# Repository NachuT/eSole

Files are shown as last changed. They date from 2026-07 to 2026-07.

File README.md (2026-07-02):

# eSole
## The idea

All of these moments were showstopping and unexpected moments in the NBA for the wrong reasons. When the sports entertainment industry id built around creating these emotions: Achilles Tears, ACL injuries, and permanent knee issues were not how they intended to create those emotions. Like many injuries, leg injuries as well benefit greatly from early detection but many players and people too don't know when things start to go wrong until they actually do. If only there was a unnoticable shoesole that can tell atheletes and people what is wrong with their mechanics.

## Now there is!

eSole is a flex PCB + Rigid PCB that measures capacitance between 2 halves of the flex PCB around foam to detect when and where pressure on the foot is being applied and where it is being applied.

Features:
- ESP32 for processing and sending analytics via bluetooth
- Both halves of the flexpcb integrated into 1 for cost
- MRP121 for sending capacitance values via I2C
- A case that is easily removable
- Power managment so the device can use a lipo but can be charged + programmed via USB-C

## Images 
PCB Footsole -



3d View Footsole-



Schematic Transmitter (ESP32 Based)-



PCB Transmitter(ESP32 Based)-



3D View PCB Transmitter(ESP32 Based)-



PCB Transmitter(ESP32 Baesed) With Case-

Screenshot 2026-07-01 at 2 05 06 AM

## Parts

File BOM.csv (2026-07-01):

Name | Price | Notes
Both PCBs | 181.37 | The rigid pcb is really optimized but the flex pcb super expensive
Shipping | 46 | For both PCBs
Customs | 60 | For both PCBs
Discount | -10 | For the PCBs
Sales Tax | 18 | For the PCBs
LiPo | 8 | https://www.amazon.com/battery-Rechargeable-Lithium-Polymer-Connector/dp/B07BTT6N48
Neoprene(best conductive foam) | 18 | https://www.homedepot.com/p/Rubber-Cal-Closed-Cell-Sponge-Rubber-Neoprene-1-16-in-x-39-in-x-78-in-Black-Foam-Rubber-Sheet-02-128-0062/304363420
- | - | -
Total | 325

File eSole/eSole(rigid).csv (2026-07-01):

Item # | Quantity per board | Comment | Reference designators | Footprint | Value | Manufacturer Part | Manufacturer | Supplier Part | Supplier | Unique ID | Pin Count | Category | LCSC Stock | LCSC Price | JLCPCB Stock | JLCPCB Price | Layer | Mounting Style | Add into BOM | Convert to PCB | 3D Model Title | Device | Name | 3D Model Transform | JLCPCB Part Class | Description | sourceId | spicePre
1 | 7 | 100nF | C1,C2,C5,C7,C13,C15,C16 | C0402 | 100nF | CL05B104KO5NNNC | SAMSUNG(三星) | C1525 | LCSC | gge14,gge15,gge20,gge20_0,gge20_1,gge20_3,gge20_4 | 2 | Capacitors:Multilayer Ceramic Capacitors MLCC - SMD/SMT |  |  | 30747172 | 0.0004 | T | SMT | yes |  | C0402_L1.0-W0.5-H0.5 | CL05B104KO5NNNC | 100nF | 39.37,19.685,0,0,0,0,0,0,0 | Basic Part | Capacitance:100nF Tolerance:±10% Tolerance:±10% Voltage Rating:16V Temperature Coefficient:X7R
2 | 6 | 1uF | C3,C4,C6,C8,C12,C14 | C0402 | 1uF | CL05A105KA5NQNC | SAMSUNG(三星) | C52923 | LCSC | gge16,gge17,gge21,gge21_0,gge21_1,gge21_2 | 2 | Capacitors:Multilayer Ceramic Capacitors MLCC - SMD/SMT |  |  | 9758515 | 0.0033 | T | SMT | yes |  | C0402_L1.0-W0.5-H0.5 | CL05A105KA5NQNC | 1uF | 39.37,19.685,0,0,0,0,0,0,0 | Basic Part | Capacitance:1uF Tolerance:±10% Tolerance:±10% Voltage Rating:25V Temperature Coefficient:X5R
3 | 2 | 4.7uF | C9,C10 | C0402 | 4.7uF | CL05A475MP5NRNC | SAMSUNG(三星) | C23733 | LCSC | gge24,gge25 | 2 | Capacitors:Multilayer Ceramic Capacitors MLCC - SMD/SMT |  |  | 2176604 | 0.0045 | T | SMT | yes |  | C0402_L1.0-W0.5-H0.5 | CL05A475MP5NRNC | 4.7uF | 39.37,19.685,0,0,0,0,0,0,0 | Basic Part | Capacitance:4.7uF Tolerance:±20% Tolerance:±20% Voltage Rating:10V Temperature Coefficient:X5R
4 | 1 | 10uF | C11 | C0603 | 10uF | CL10A106KP8NNNC | SAMSUNG(三星) | C19702 | LCSC | gge27 | 2 | Capacitors:Multilayer Ceramic Capacitors MLCC - SMD/SMT |  |  | 5635641 | 0.0065 | T | SMT | yes |  | C0603_L1.6-W0.8-H0.8 | CL10A106KP8NNNC | 10uF | 62.992,31.496,0,0,0,0,0,0,0 | Basic Part | Capacitance:10uF Tolerance:±10% Tolerance:±10% Voltage Rating:10V Temperature Coefficient:X5R
5 | 1 | S2B-PH-SM4-TB(LF)(SN) | CN1 | CONN-SMD_P2.00_S2B-PH-SM4-TB-LF-SN |  | S2B-PH-SM4-TB(LF)(SN) | JST | C295747 | LCSC | gge6 | 4 | Connectors:Wire To Board Connector |  |  | 99038 | 0.0303 | T | SMT | yes |  | CONN-SMD_P2.00_S2B-PH-SM4-TB-LF-SN | S2B-PH-SM4-TB(LF)(SN) | S2B-PH-SM4-TB(LF)(SN) | 311.023,338.582,0,0,0,0,0,-3.937,0 | Extended Part | Pins Structure:1x2P Pitch:2mm Mounting Style:Horizontal attachment Reference Series:PH Number of Pins:2P Number of Rows:1 Number of PINs Per Row:2 Row Spacing:- Current Rating (Max):2A Contact Material:Copper alloy Contact Plating:Tin Operating Temperatur
6 | 2 | SS34 | D1,D2 | SMA_L4.3-W2.6-LS5.2-RD |  | SS34 | MDD(辰达半导体) | C8678 | LCSC | gge12,gge13 | 2 | Diodes:Schottky Diodes |  |  | 3261153 | 0.0047 | T | SMT | yes |  | SMA_L4.3-W2.6-LS5.2-RD | SS34_C8678 | SS34 | 185.039,102.362,0,0,0,0,0,0,0 | Basic Part | Diode Configuration:Independent Voltage - Forward(Vf@If):550mV@3A Voltage - DC Reverse(Vr):40V Current - Rectified:3A Reverse Leakage Current (Ir):500uA@40V Operating Junction Temperature Range:-55℃~+125℃ Operating Junction Temperature Range:-55℃~+125℃
7 | 1 | FPC-05F-12PH20 | FPC1 | FPC-SMD_12P-P0.50_FPC-05F-12PH20 |  | FPC-05F-12PH20 | XUNPU(讯普) | C2856799 | LCSC | gge2 | 14 | Connectors:FFC, FPC (Flat Flexible) Connector Assemblies |  |  | 123048 | 0.0154 | T | SMT | yes |  | FPC-SMD_12P-P0.50_FPC-05F-12PH20 | FPC-05F-12PH20 | FPC-05F-12PH20 | 409.448,201.5744,0,0,0,0,0,-47.244,0 | Extended Part | Locking Feature:Hinged Lid Contact Type:Surface Mount Number of Contacts:12P Pitch:0.5mm Mounting Type:Bottom Contact FFC, FCB Thickness:0.3mm FFC, FCB Thickness:0.3mm Height Above Board:2mm Contact Material:Phosphor Bronze Contact Plating:Tin Operating T
8 | 1 | KT-0603W | LED1 | LED0603-R-RD_WHITE |  | KT-0603W | KENTO | C2290 | LCSC | gge26 | 2 | Optoelectronics:LED Indication - Discrete |  |  | 1996819 | 0.0019 | T | SMT | yes |  | LED0603-R-RD_WHITE | KT-0603W | KT-0603W | 63.7794,31.496,0,0,0,0,0,0,0 | Basic Part | Lamp Holder Type:1.6mm x 0.8mm square LED Illumination Color:White Voltage - Forward(Vf):2.6V~3.1V Voltage - Forward(Vf):2.6V~3.1V Power(Watts):100mW Forward Current:5mA Wavelength - Dominant:- Wavelength - Dominant:- Peak Wavelength:- Peak Wavelength:- D
9 | 2 | 5.1kΩ | R1,R2 | R0402 | 5.1kΩ | 0402WGF5101TCE | UNI-ROYAL(厚声) | C25905 | LCSC | gge10,gge11 | 2 | Resistors:Chip Resistor - Surface Mount |  |  | 1798751 | 0.0002 | T | SMT | yes |  | R0402_L1.0-W0.5-H0.4 | 0402WGF5101TCE | 5.1kΩ | 39.37,19.685,0,0,0,0,0,0,0 | Basic Part | Type:Thick Film Resistor Resistance:5.1kΩ Tolerance:±1% Tolerance:±1% Power(Watts):62.5mW Voltage-Supply(Max):50V Temperature Coefficient:±100ppm/℃ Temperature Coefficient:±100ppm/℃ Operating Temperature:-55℃~+155℃ Operating Temperature:-55℃~+155℃
10 | 2 | 0Ω | R3,R4 | R0402 | 0Ω | 0402WGF0000TCE | UNI-ROYAL(厚声) | C17168 | LCSC | gge18,gge19 | 2 | Resistors:Chip Resistor - Surface Mount |  |  | 2705757 | 0.0003 | T | SMT | yes |  | R0402_L1.0-W0.5-H0.4 | 0402WGF0000TCE | 0Ω | 39.37,19.685,0,0,0,0,0,0,0 | Basic Part | Type:Thick Film Resistor Resistance:0Ω Tolerance:±1% Tolerance:±1% Power(Watts):62.5mW Voltage-Supply(Max):50V Temperature Coefficient:±800ppm/℃ Temperature Coefficient:±800ppm/℃ Operating Temperature:-55℃~+155℃ Operating Temperature:-55℃~+155℃
11 | 1 | 2kΩ | R5 | R0402 | 2kΩ | 0402WGF2001TCE | UNI-ROYAL(厚声) | C4109 | LCSC | gge22 | 2 | Resistors:Chip Resistor - Surface Mount |  |  | 1410006 | 0.0002 | T | SMT | yes |  | R0402_L1.0-W0.5-H0.4 | 0402WGF2001TCE | 2kΩ | 39.37,19.685,0,0,0,0,0,0,0 | Basic Part | Type:Thick Film Resistors Resistance:2kΩ Tolerance:±1% Tolerance:±1% Power(Watts): Overload Voltage (Max): Temperature Coefficient:±100ppm/℃ Temperature Coefficient:±100ppm/℃ Operating Temperature Range:-55℃~+155℃ Operating Temperature Range:-55℃~+155℃
12 | 1 | 470Ω | R6 | R0402 | 470Ω | 0402WGF4700TCE | UNI-ROYAL(厚声) | C25117 | LCSC | gge23 | 2 | Resistors:Chip Resistor - Surface Mount |  |  | 501753 | 0.0002 | T | SMT | yes |  | R0402_L1.0-W0.5-H0.4 | 0402WGF4700TCE | 470Ω | 39.37,19.685,0,0,0,0,0,0,0 | Basic Part | Type:Thick Film Resistor Resistance:470Ω Tolerance:±1% Tolerance:±1% Power(Watts):62.5mW Voltage-Supply(Max):50V Temperature Coefficient:±100ppm/℃ Temperature Coefficient:±100ppm/℃ Operating Temperature:-55℃~+155℃ Operating Temperature:-55℃~+155℃
13 | 2 | 10kΩ | R7,R8 | R0402 | 10kΩ | 0402WGF1002TCE | UNI-ROYAL(厚声) | C25744 | LCSC | gge28,gge29 | 2 | Resistors:Chip Resistor - Surface Mount |  |  | 217303 | 0.0005 | T | SMT | yes |  | R0402_L1.0-W0.5-H0.4 | 0402WGF1002TCE | 10kΩ | 39.37,19.685,0,0,0,0,0,0,0 | Basic Part | Type:Thick Film Resistor Resistance:10kΩ Tolerance:±1% Tolerance:±1% Power(Watts):62.5mW Voltage-Supply(Max):50V Temperature Coefficient:±100ppm/℃ Temperature Coefficient:±100ppm/℃ Operating Temperature:-55℃~+155℃ Operating Temperature:-55℃~+155℃
14 | 1 | 75kΩ | R9 | R0603 | 75kΩ | 0603WAF7502T5E | UNI-ROYAL(厚声) | C23242 | LCSC | gge30 | 2 | Resistors:Chip Resistor - Surface Mount |  |  | 199044 | 0.0003 | T | SMT | yes |  | R0603 | 0603WAF7502T5E | 75kΩ | 31.8897,63.7794,0,90,0,0,0,0,0 | Basic Part | Type:Thick Film Resistor Resistance:75kΩ Tolerance:±1% Tolerance:±1% Power(Watts):100mW Voltage-Supply(Max):75V Temperature Coefficient:±100ppm/℃ Temperature Coefficient:±100ppm/℃ Operating Temperature:-55℃~+155℃ Operating Temperature:-55℃~+155℃
15 | 2 | 4.7kΩ | R10,R11 | R0805 | 4.7kΩ | 0805W8F4701T5E | UNI-ROYAL(厚声) | C17673 | LCSC | gge31,gge32 | 2 | Resistors:Chip Resistor - Surface Mount |  |  | 2978214 | 0.0005 | T | SMT | yes |  | R0805_L2.0-W1.3-H0.6 | 0805W8F4701T5E | 4.7kΩ | 78.74,51.181,0,0,0,0,0,-0.0005,0 | Basic Part | Type:Thick Film Resistors Resistance:4.7kΩ Tolerance:±1% Tolerance:±1% Power(Watts): Overload Voltage (Max): Temperature Coefficient:±100ppm/℃ Temperature Coefficient:±100ppm/℃ Operating Temperature Range:-55℃~+155℃ Operating Temperature Range:-55℃~+155℃
16 | 2 | TS-1088-AR02016 | SW1,SW2 | SW-SMD_L3.9-W3.0-P4.45 |  | TS-1088-AR02016 | XUNPU(讯普) | C720477 | LCSC | gge4,gge5 | 2 | Switches:Tactile Switches |  |  | 871138 | 0.0083 | T | SMT | yes |  | SW-SMD_L3.9-W2.9-H2.0-LS4.8 | TS-1088-AR02016 | TS-1088-AR02016 | 188.976,114.174,0,0,0,0,0,0,0 | Basic Part | Circuit:SPST Actuator Style:Round Button Operating Force:1.6N Mounting Type:Surface Mount,Vertical Length:3.9mm Width:3mm Switch Height:2mm with Bracket:Without Bracket Contact Current:50mA Voltage Rating:12V Actuator/Cap Color:Black With Lamp:- IP Rating
17 | 1 | 2.4GHz | U1 | WIFIM-SMD_ESP32-S3-WROOM-1-N8 | 2.4GHz | ESP32-S3-WROOM-1-N8 | ESPRESSIF(乐鑫) | C2913198 | LCSC | gge1 | 49 | IoT/Communication Modules:WiFi Modules |  |  | 7521 | 0.7148 | T | SMT | yes |  | WIFIM-SMD_ESP32-S3-WROOM-1-N8 | ESP32-S3-WROOM-1-N8 | 2.4GHz | 708.66,1003.935,0,0,0,0,0,145.669,0 | Extended Part | Utilized IC / Part:ESP32-S3 Chip Wireless Standard:Bluetooth5.0 Interface Type:SPI；I2S；USB；I2C；UART Frequency:2.4GHz Antenna Type:On-board PCB Antenna Output Power:20.5dBm Output Power:20.5dBm Voltage - Supply:3V~3.6V Voltage - Supply:3V~3.6V Receive Cur
18 | 1 | MPR121QR2 | U2 | QFN-20_L3.0-W3.0-P0.40-BL |  | MPR121QR2 | NXP(恩智浦) | C91322 | LCSC | gge7 | 20 | Sensors:Touch Sensors |  |  | 1879 | 0.3987 | T | SMT | yes |  | QFN-20_L3.0-W3.0-H0.6-P0.40-BL | MPR121QR2 | MPR121QR2 | 118.11,118.11,0,90,0,0,0.005,0,0 | Extended Part | Number of Channels:12 Chip Function:Capacitive Touch Voltage - Supply:1.71V~3.6V Voltage - Supply:1.71V~3.6V Current - Supply:29uA Operating Temperature:-40℃~+85℃ Operating Temperature:-40℃~+85℃ Standby Current:3uA ESD Protection Voltage:2kV
19 | 1 | MCP73831T-2DCI/OT | U3 | SOT-23-5_L2.9-W1.6-P0.95-LS2.8-BL |  | MCP73831T-2DCI/OT | MICROCHIP(美国微芯) | C625597 | LCSC | gge8 | 5 | Power Management (PMIC):Battery Management |  |  | 1373 | 0.1565 | T | SMT | yes |  | SOT-23-5_L2.9-W1.6-P0.95-LS2.8-BL | MCP73831T-2DCI/OT | MCP73831T-2DCI/OT | 114.96,110.236,0,0,0,0,0,0,0 | Extended Part | The Chip Type:Charging IC Voltage - Supply:3.75V~6V Voltage - Supply:3.75V~6V Charge Current - Max:550mA Charging Saturation Voltage:4.2V End-Off Voltage:- Type of Battery:Lithium Battery Number of Cells:1 Number of Cells:1 Operating Temperature:-40℃~+85℃
20 | 1 | XC6206P332MR-G | U4 | SOT-23-3_L2.9-W1.6-P1.90-LS2.8-BR |  | XC6206P332MR-G | TOREX(特瑞仕) | C5446 | LCSC | gge9 | 3 | Power Management (PMIC):Voltage Regulators - Linear, Low Drop Out (LDO) Regulators |  |  | 550052 | 0.0175 | T | SMT | yes |  | SOT-23-3L_L2.9-W1.6-H1.1-LS2.8-P0.95 | XC6206P332MR-G_C5446 | XC6206P332MR-G | 114.173,110.236,0,90,0,0,0,0,0 | Basic Part | Output Configuration:Positive Voltage - Supply:6V Output Voltage:3.3V Output Voltage:3.3V Output Current:200mA Power Supply Rejection Ratio (PSRR):- Voltage Dropout:- standby current:1uA Noise:- Features:Short Circuit Protection；Over Current Protection Op
21 | 1 | TYPE-C16PIN | USB1 | USB-C-SMD_TYPE-C16PIN |  | TYPE-C16PIN | SHOU HAN(首韩) | C393939 | LCSC | gge3 | 16 | Connectors:USB Connectors |  |  | 468999 | 0.0102 | T | DIP | yes |  | USB-C-SMD_TYPE-C16PIN | TYPE-C16PIN | TYPE-C16PIN | 351.9678,311.023,0,180,0,0,0,-41.85,-39.37 | Extended Part | Connector Type:Type-C Protocol Standard:- Gender:Female Mounting Type:Surface Mount, Right Angle Number of Contacts:16P Number of Ports:1 Current Rating-Power:3A Voltage Rating:30V Connect-Disconnect Life:10,000 Cycles Supplementary Features:- Center Heig

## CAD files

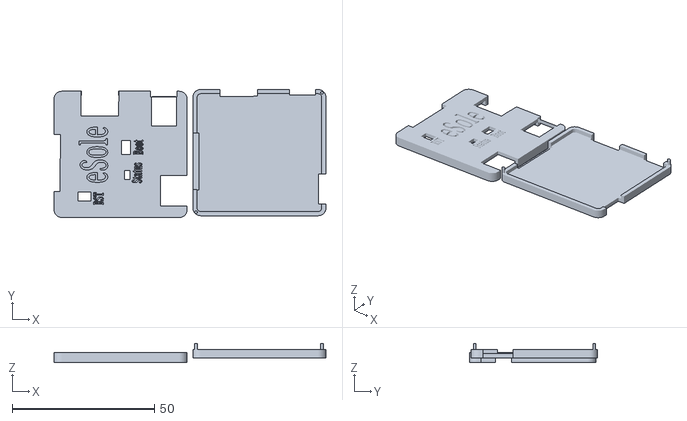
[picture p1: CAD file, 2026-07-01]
CAD/CAD.stl
95.6 x 45.0 x 6.79

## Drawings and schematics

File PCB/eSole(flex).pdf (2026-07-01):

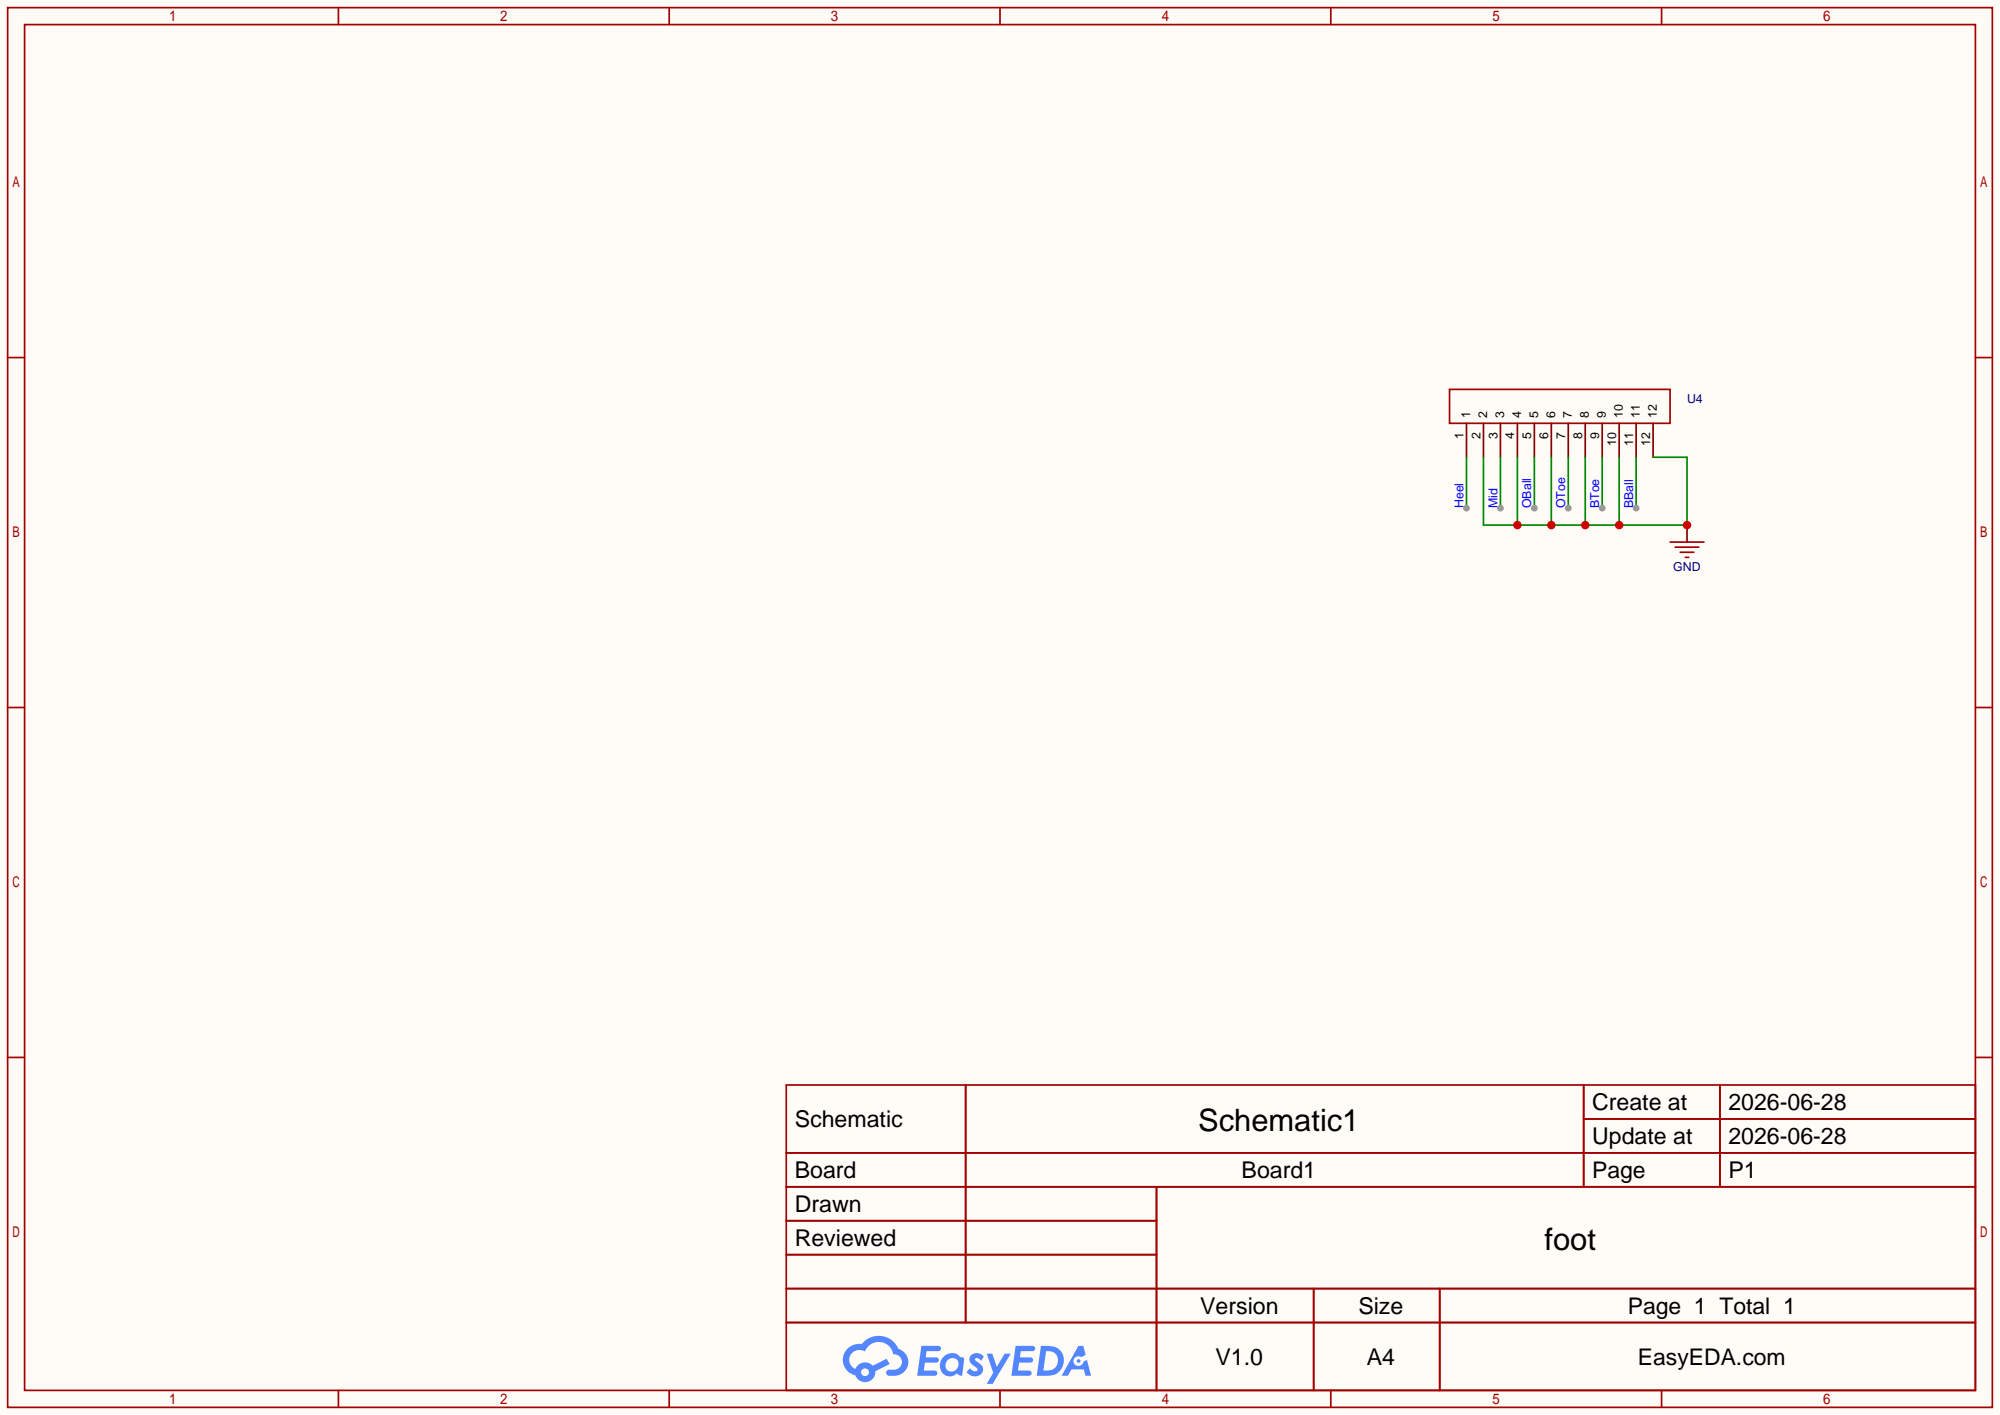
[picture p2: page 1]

Schematic | Schematic1 | Create at | 2026-06-28

Update at | 2026-06-28

Board | Board1 | Page | P1
Drawn | | foot
Reviewed

Version | Size | Page 1 Total 1
V1.0 | A4 | EasyEDA.com

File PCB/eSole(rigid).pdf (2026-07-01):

IO0 27 IO35 28 IO36 29 IO37 30 IO38 31 IO39 32 IO40 33 IO41 34 IO42 35 RXD0 36 TXD0 37 IO2 38 IO1 39 GND 40

ESP-32 | FPC

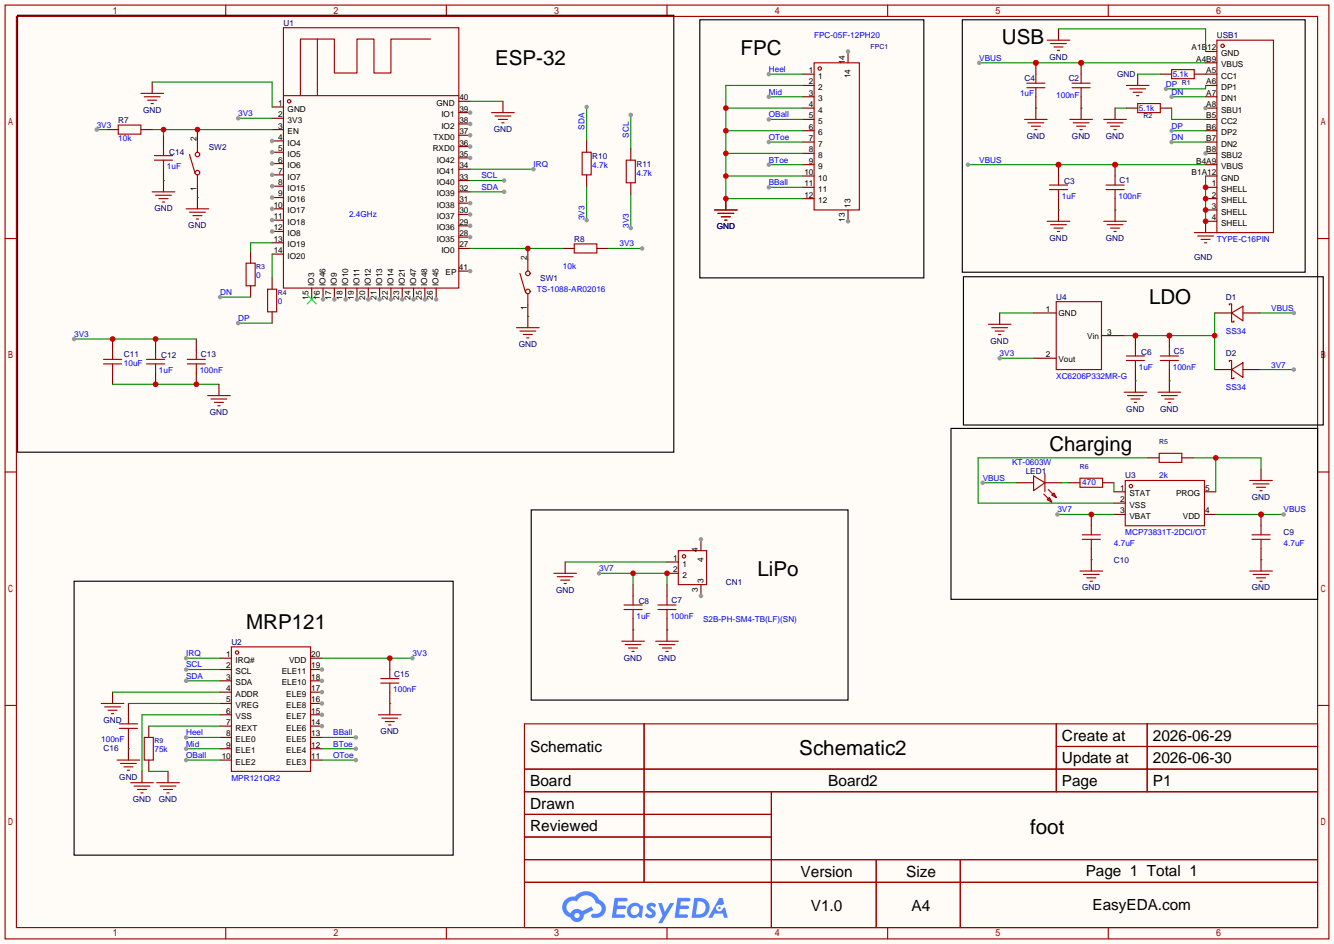
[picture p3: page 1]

Schematic | Schematic2 | Create at | 2026-06-29

Update at | 2026-06-30

Board | Board2 | Page | P1
Drawn | | foot
Reviewed

Version | Size | Page 1 Total 1
V1.0 | A4 | EasyEDA.com

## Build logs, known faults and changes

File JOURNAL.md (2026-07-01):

# Trying my best to do cad

_Time spent: 5h_

Cad is so annoying because I know how to use fusion (just barely) and have no clue how to use onshape so I am stuck jumbing around between different softwares just to make a box. I made most of it in fusion but at then end of it my fusion started bugging and removed my progress randomly because my pcb was too difficult to render so I just had to use a online viewer and make sure they matched up. After this I just put it into tinkercad to add some text because I was too lazy to do it in fusion.
fe



# Grinded out all of the PCB

_Time spent: 3h_

Honestly the components were a lot bigger than i thought they would be making it harder to fit in all of my things but I generally found a good place for everything to go with the reset button being left of the antenna all the power stuff opposite of antenna and all of the sensor i2c stuff on the right of the antenna. I then compressed the power stuff as much as I could before I started routing. I started with the USB differential pair which took me around 5-6 tries but I was eventually able to place the 0 ohm resistors just right to get a good differential pair. From here it was pretty smooth sailing slight adjustments here and there obviously I kept my power traces thicker and routed out to the rest of the board. Once I got to the final electrode section it was honestly pretty tight but I was able to just 45 dgeree rotate the MRP121 giving it a nice routing into the pins of the mcu and the fpc connector. After this I just filleted the edges placed the ground planes stitching vias and adjusted the planes a bit to get some more area for vias then added silskcreen to finish of the electronics of this proejct




# Finished Schematic

_Time spent: 1h_

This part of the project was not that bad at all since all I had to do was read the esp32 documentation carefully and make sure I didnt accidentally use one of the strapping pins and other than that I just basically followed the datasheet. I did end up redoing where I decided to place I2C tho because I realized that based on the layout i planned earlier it would be easier to route this way instead. Lastly of course I routed the FPC and mrp121 which was thankfully pretty easy not too many passsives or anything because of its autoconfig.




# Research(short) + Half the Schematic for second board

_Time spent: 2.5h_

Now I was thinking about this phase for a pretty long time tbh so I aleardy knew a lot on what I wanted to do but just did some short around 30 min research on the perfect FPC ZIF connector for this project which I eventually found. I also chose to use a 3.7V Lipo w USB-C charging via a usb pwr management ic and use 2 diodes to make sure the mcu i chose (esp32 s3 wroom) didn't get 2 power sources at once. The charging circuit was a little weird and I asked for some help w it and looked at some public schematics but I eventually got it I think.




# Routing the actual Foot

_Time spent: 7h_

To start off what I did was route out all of the traces in the fpc out to the main part pretty simple but I had to adjust some of my board outlines to avoid drc errors. From there I imported this image I found online that allowed me better recognize and draw the different zones I needed to measure and did my best to resize this to my pcb and use the polygon tool while this was on silkscreen(remember this) to get the rough shapes around it. 

Okay so then I had all of the different regions zones out I had grounds that I would just via stitch later and my signals just flowed pretty effortlessly into each of the copper regions. I then constructed a way for me to reflect these onto the other half of the insole which I am pretty proud of. So what I did was place a temp via at the center of the rectangularish region that connected the 2 sides of the insole together and then what I would do is on the region itslef I would copy and paste the same region exactly on top and rotate the copy 180 on top of itself then I would reflect vertically ABOUT the temp via point  giving near perfect placements. After this I heard that since that top side would have the gnd regions as well as a general vgnd plane it is good practice to use vias around the regions to sort of isolate them and make it so their signals are the ones that matter which was tedious but pretty easy. 

Now lastly it was time to place the hateched ground planes but they were going everywhere all over the place like way beyond the board edges. I deteled some of the regions reset my editor renamed the ground net and did as much as I could to get this to work but always it never fixed itself. Then after so much frustration I realized that a super small amount of the board outline became silkscreen when I turned that other image earlier into silkscreen which wasted like literally an hour of my time tryign to figure that out. 

After that, I did some more research because I wasn't sure whether I should have a hatched region around my capactive pads and figured that it didn't provide any actual stability and it was just better to not use it as it could lead to the signal coupling with that ground rather than the region itself. At the end of this I just did some final adjustment work like deleting the random temportary stuff and rebuilding some of the planes to end of at this.





# Schematic (but not really) and Outline of the board

_Time spent: 3h_

I first started out with the schematic which was very fast as all I really had to do was descide on what 6 major foot zones I wanted to track.

After this I went to my physical shoe and took out the shoesole took a photo and adjusted with the outlining of it so that the only part that is outlined is the actual borders itself. After this I then exported that as a DXF reimported it into Easyeda and had to relearn some of the alignment reflection rotation stuff that I learned a while back from a youtube video to duplicate the other half of the shoe insole onto the other side and line them up just right. After this I had to connect those 2 halves together which involved cutting up that original dxf into a dxf without that hole reduplicating + aligning it and drawing a board line to connect the 2 halves togther. I also saved some time by making sure to make a hole for the ribbon calble to go out as well. Lastly, I read that it was bad to have 90 degree beends and to instead have curved bends so I went back in deleted some lines and used the 3 point polyarc tool to make the board outline.





# Lots of random second guessing

_Time spent: 3h_

I made a pretty important descision that it is not safe to have a Lipo Battery near my foot and I would have to make an external PCB to fold up and out the ankle region to connect to the pcb. For this I had 2 options that I came up with JST connectors and a FPC ribbon cable. The ribbon cable is much cheaper and easier to manufacture but higherchance I mess up but the JST connector is more expensive harder to source everything but high chance it works. I spent 30 mins here and 30 mins there doing research for either one before finally deciding to settle on the ribbon cable primarily for cost. I then also had another dilema as in my research I heard about approaching this with FSRs( Force sensitive resistors) which simplifies a lot of the process and I think could also help increase the likeliehood this works. I actually did a lot of research on how to integreate fsrs but thankfully I found out that JLCPCB maxes out at around 10kg of force so there was no way that was an option anymore.


just ended up reusing this for easyeda lol



# Research init

_Time spent: 4h_

So if you have seen my most recent project my capacitive touch sesnor based rubiks cube you will know that I wish that I used a continous capacitive sensor rather than the binary (on/off sensor) that I was using. So while I was thinking about what cool applications for a MRP121 that I could use were and since I have been playing a lot of basketaball recently I remembered watching https://www.youtube.com/watch?v=yaZKmCq6sRQ a while back and chose to use the context of capacitance for this PCB. The idea is there is a flex pcb with a esp32 that relays the infoform the mrp121 and I can (hopefully) fit all of the elctronics into the midfoot(the part that is usually arched) so it doesnt actually break but is wearable. For more information on the actual capacitive sensor I read Practical electronics for inventors and their chapter on conductivity and dielectric constants and a whole lot of other stuff I tried my best to understand lol
